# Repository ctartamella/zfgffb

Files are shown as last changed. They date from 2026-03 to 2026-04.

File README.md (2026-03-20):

# Team ZFG Active Pedal Design

This repository contains an amalgamation of DIY pedal designs from around the Internet to create a single optimal pedal design with thorough documentation and the most up to date feature set.

This includes:

* Gilphilbert V2 board
* XT30 connectors with simpler wiring
* 350W and 600W PSU options
* Multiple pedal options
* Complete BOM for all scenarios
* Easy to follow instructions

## Project Offerings

Included in this project's releases are a few key artifacts to help you build

* A full 3MF file for 3D printing including print settings.
* A full BOM covering various power supply and pedal options

Also included is a Wiki with full instructions to build this pedal for yourself.

## License

This design is licensed under CC BY-NC-SA 4.0.  This work would not be possible without the contributions of some very talented individuals.

* ChGri's orginal DIY FFB Pedal design [GitHub](https://github.com/ChrGri/DIY-Sim-Racing-FFB-Pedal)
* ChrisJamesChamp's design and wonderful documentation [GitHub](https://github.com/chrisjameschamp/DIY-Active-Pedal-Design)
* Gilphilbert's v2 PCB Designs [GitHub](https://github.com/gilphilbert/DIY-Sim-Racing-FFB-Pedal-PCBs)
* Additional modifications by Discord User Dud from the FFB Pedal [Discord](https://discord.com/channels/1113129142142120159/1390021016717361294)
* Custom CAD designs by ZFG member Alex Rich

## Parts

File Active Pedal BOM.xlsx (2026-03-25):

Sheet: Group Buy
Group | Part Name | Quantity Needed | Quantity per Unit | Total Needed | Units Needed | Cost | Subcost | Qty / Share
M3 | M3x0.5 5mm Flat | 2 | 50 | 14 | 1 | 7.29 | 7.29 | 7
 | M3x0.5 Insert | 15 | 100 | 105 | 2 | 8.69 | 17.38 | 28
 | M3x0.5 6mm SHCS | 4 | 120 | 28 | 1 | 7.99 | 7.99 | 17
 | M3x0.5 20mm SHCS | 2 | 100 | 14 | 1 | 6.96 | 6.96 | 14
 | M3x0.5 16mm Flat | 6 | 100 | 42 | 1 | 8.28 | 8.28 | 14
 | M3x0.5 14mm Flat head screw | 4 | 100 | 28 | 1 | 8.28 | 8.28 | 14
 | M3x0.5 18mm Flat head screw | 2 | 50 | 14 | 1 | 7.59 | 7.59 | 7
 | M3x0.5 30mm Flat | 1 | 100 | 7 | 1 | 8.68 | 8.68 | 14
 | M3 Square Nut | 2 | 200 | 14 | 1 | 6.99 | 6.99 | 28
 | M3x0.5 10mm Flat | 2 | 100 | 14 | 1 | 7.69 | 7.69 | 14
M4 | M4x0.7 Inserts | 12 | 50 | 84 | 2 | 9.99 | 19.98 | 14
 | M4x0.7 6mm Flat Head | 2 | 50 | 14 | 1 | 7.99 | 7.99 | 7
 | M4x0.7 14mm Flat Head | 16 | 100 | 112 | 2 | 9.49 | 18.98 | 28
 | M4x0.7 Nut | 4 | 100 | 28 | 1 | 5.69 | 5.69 | 14
 | M4x0.7 14mm Socket Head Screw | 2 | 120 | 14 | 1 | 8.99 | 8.99 | 17
 | M4x0.7 10mm Flat head screw | 10 | 50 | 70 | 2 | 6.89 | 13.78 | 14
 | M4x0.7 30mm Socket Head Screw | 2 | 50 | 14 | 1 | 8.46 | 8.46 | 7
M5 | M5x0.8 18mm SHCS | 2 | 50 | 14 | 1 | 8.86 | 8.86 | 7
 | M5x0.8 nut | 0 | 200 | 0 | 0 | 9.99 | 0 | 0
 | M5x08 40mm SHCS | 4 | 30 | 28 | 1 | 8.11 | 8.11 | 4
 | M5x0.8 Insert | 6 | 50 | 42 | 1 | 9.99 | 9.99 | 7
 | M5x0.8 14mm SHCS | 2 | 50 | 14 | 1 | 8.96 | 8.96 | 7
 | M5x0.8 45mm SHCS | 2 | 25 | 14 | 1 | 7.99 | 7.99 | 3
 | M5x0.8 16mm Flat Head | 2 | 50 | 14 | 1 | 8.28 | 8.28 | 7
 | M5 Steel Finish Washer | 2 | 30 | 14 | 1 | 9.99 | 9.99 | 4
M6 | M6 Nuts | 6 | 50 | 42 | 1 | 6.19 | 6.19 | 7
 | M6 Washers | 6 | 100 | 42 | 1 | 5.19 | 5.19 | 14
M8 | M8 Nylock Nut | 2 | 20 | 14 | 1 | 5.99 | 5.99 | 2
 | M8 15mm Button Head | 2 | 30 | 14 | 1 | 8.54 | 8.54 | 4
 | M8x1.25 18mm SHCS | 2 | 20 | 14 | 1 | 8.99 | 8.99 | 2
M2.5 | M2.5x0.4 6mm SHCS | 4 | 50 | 28 | 1 | 6.19 | 6.19 | 7
Misc | 608 ZZ Bearing | 6 | 20 | 42 | 3 | 6.99 | 20.97 | 8
 | 8mm x 40mm Dowel Pin | 1 | 10 | 7 | 1 | 9.69 | 9.69 | 1
 | 8mm OD 4.2mm ID 30mm spacer | 1 | 20 | 7 | 1 | 26 | 26 | 2
 | Silicon Tubing |  |  |  | 1 | 11.59 | 11.59
 | Number of Shares | 7 |  |  |  | SUB TOTAL | 342.52
 | Alex | 1 |  |  |  | TAX | 11.96
 | Chris | 3 |  |  |  | TOTAL | 354.48
 | Jeff | 3 |  |  |  | SHARE PRICE | 50.64

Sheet: Individual Purchases
Category | Part | Price | Quantity | Part Number | Notes | Link
Pedal | Linear rail (Brake) | 71 | 1 | JKK60-5-P-150-A1-F4-M | For the same price, getting the 5P version (5mm pitch aka moves 5mm per rotation) is fine | https://jlcmc.com/product/s/B16/BQD-JKK60/FA-%E7%9B%B4%E7%BA%BF%E8%BF%90%E5%8A%A8%E9%9B%B6%E4%BB%B6-%E9%92%A2%E5%88%B6%E7%9B%B4%E7%BA%BF%E6%A8%A1%E7%BB%84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
 | Linear rail (Throttle/Clutch) | 71 | 1 | JKK60-10-P-150-A1-F4-M | Note which is which however for SimHub setup as it is a parameter. | https://jlcmc.com/product/s/B16/BQD-JKK60/steel-linear-actuators-kk60-series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
 | 130w NEMA 23 Servo Motor | 82 | 1 | iSV57T-130S |  | https://www.omc-stepperonline.com/nema-23-integrated-easy-servo-motor-130w-3000rpm-0-45nm-63-73oz-in-20-50vdc-servo-motor-short-shaft-isv57t-130s
 | Load Cell | 47 | 1 | DYLY-107 200kg |  | https://a.co/d/eEIK39s
 | Aluminum base plate | 90 | 1 | SendCutSend | Cost listed was when buying 2. Buying just one will be a touch more.
350W PSU | MEANWELL LRS-350-36 | 39 |  |  | 350W PSU can support 1 and potentially 2 at your discretion | https://a.co/d/0a54GfQB
 | IEC Connector w/ Power Switch | 11 |  |  |  | https://www.mcmaster.com/5428N118/
600W PSU | IEC Connector w/ Power Switch | 11 |  |  | 600W PSU is required for 3 pedal setups. | https://www.mcmaster.com/5428N118/
 | MEANWELL LRS-600-36 | 60 |  |  |  | https://www.omc-stepperonline.com/lrs-600-36-mean-well-597-6w-36vdc-16-6a-115-230vac-enclosed-switching-power-supply-lrs-600-36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
Misc | XT 30 Wiring | 10 |  |  | You'll need pigtails for the PSU and to make custom cables depending on your setup.
 | 16 Gauge Wire | 10 |  |  | Daisy chaining is supported with the Gilphilbert boards, or you can go direct from PSU to pedal
 | Adhesive Silicon Roll | 10 | 1 |  |  | https://a.co/d/0RqzMVF
 | USB-C Extension | 10 | 1 |  |  | https://a.co/d/dT4IqKd
 | Heat Shrink Tubing
 | Dupont Wires/connector |  |  |  | Optional, but appears to be the cleanest way to connect wires to the stepper motor without soldering
Wifi | ESP32 Dev board for Wifi Bridge | 15 | 1 |  | Only 1 total is needed. | https://a.co/d/0eLUcZa6
 | RG178 U.FL MHF1 to SMA | 10 | 1 |  | 12 inch CAN work, but 14 is better albeit harder to find. | https://www.data-alliance.net/mhf1-to-rp-sma-female-cable-4-inch-6-8-10-12-14-inch-mhf1-mhf/
 | RP-SMA Male Antenna | 10 | 1 |  | 1 per pedal | https://a.co/d/09jSDpD9
Tools | Soldering Iron
 | Solder
 | Flux
 | Hammer |  |  |  | Tolerances were tight for me and this came in handy more than once.
Fasteners | M6x??? | 5 | 6 |  | Length depends on your mounting plate. 22.3mm is the length needed to reach the bottom of the plate. Add length as necessary.

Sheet: Filament Needed
Part | Classification | Filament Type | Weight Needed | Cost/Roll | Link
Pedal | Structural | PPA-CF | 1200 | 80 | https://a.co/d/01gsQgr3
Pedal | Decorative | PETG-CF | 600 | 20 | https://a.co/d/0c4b1sY0
350W PSU | All | Anything with reasonable heat resistance | 425
600W PSU | All | Anything with reasonable heat resistance | 500
 |  | For each pedal, print plates 1-6, then print pedal faces as needed (12 or 13 based on desired)
 |  | For WiFi support with the bridge, print plate 14
 |  | For 350W Power supply, print plates 7 and 8
 |  | For 600W power supply, print plates 9 and 10

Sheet: Links
 | Has Wiki with info? | Web | Discord
ChrGri's Orginal FFB Pedal Design | YES | https://github.com/ChrGri/DIY-Sim-Racing-FFB-Pedal | https://discord.gg/zTfQaxpAUz
ChrisJamesChamp's Build | YES | https://github.com/chrisjameschamp/DIY-Active-Pedal-Design | https://discord.com/channels/1113129142142120159/1350718069441429504
Dud's Build |  |  | https://discord.com/channels/1113129142142120159/1390021016717361294
Gilphilbert v2 Board | YES | https://github.com/gilphilbert/DIY-Sim-Racing-FFB-Pedal-PCBs
350W XT30 Support |  | https://makerworld.com/en/models/2140438-350w-power-supply-cover-with-xt30-connector
Simucube Pedal Design |  | https://docs.simucube.com/ActivePedal/Drawings.html
Wifi Bridge Case |  | https://makerworld.com/en/models/1456361-esp32-s3-wroom-case?from=search#profileId-1517915

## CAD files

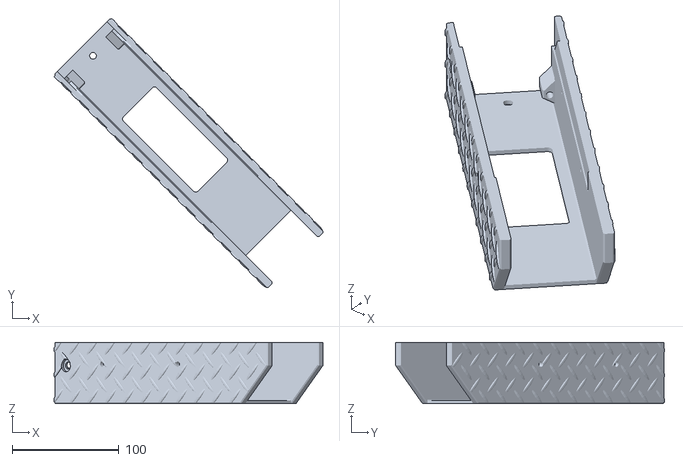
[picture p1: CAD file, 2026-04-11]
External Case/Main Cover.stl
251.5 x 251.4 x 57.5

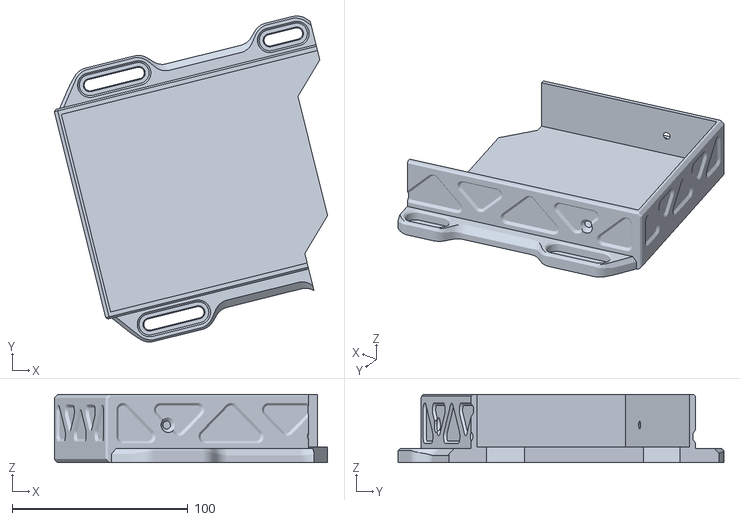
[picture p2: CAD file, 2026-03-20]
350W PSU/350W PSU IO Cover.stl
155.7 x 185.7 x 38.9

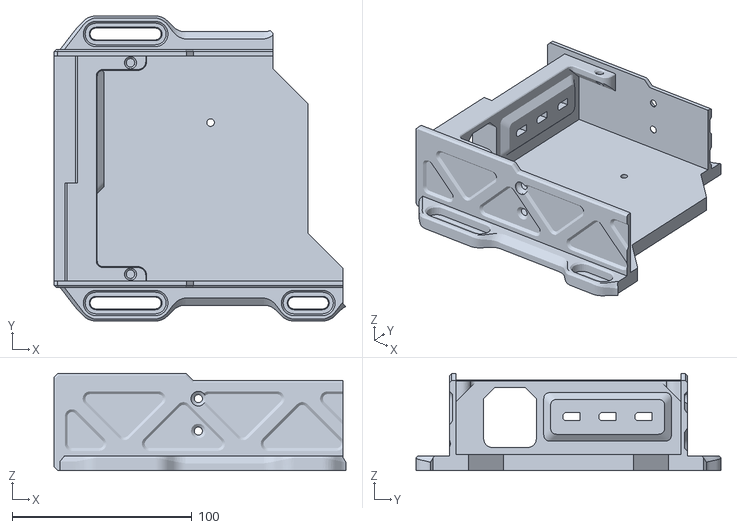
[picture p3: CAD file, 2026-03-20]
600W PSU/600W PSU Case Lower.stl
162.2 x 169.5 x 53.9

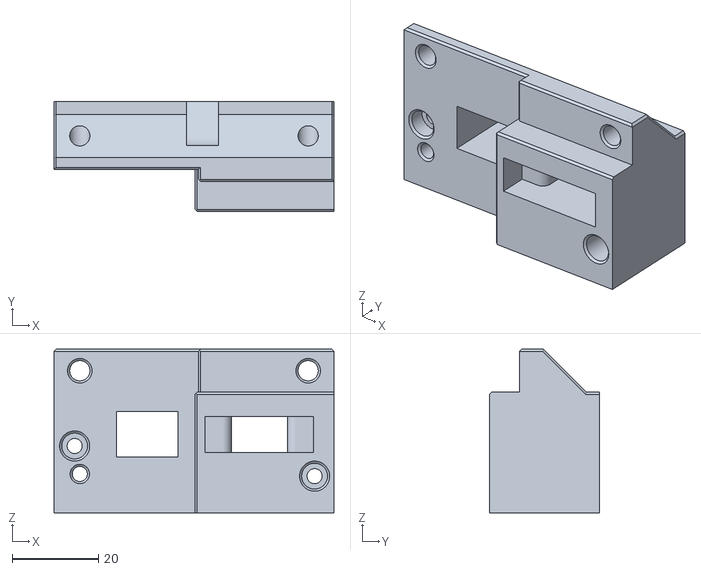
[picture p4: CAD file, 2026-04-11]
External Case/Inner IO Bracket.stl
65.1 x 25.6 x 38.0

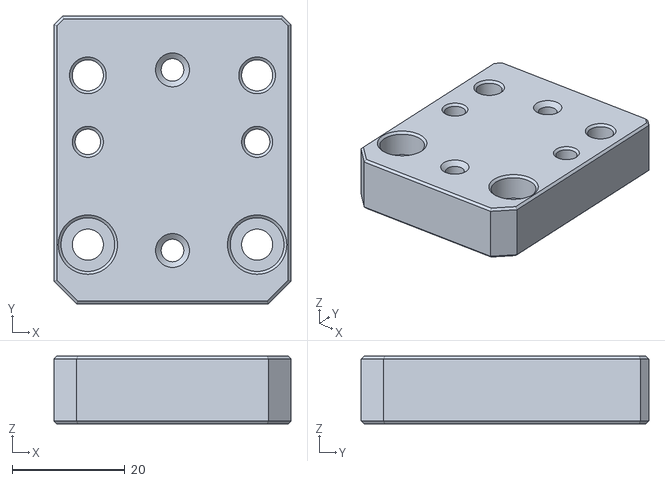
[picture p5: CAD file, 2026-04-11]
Load Cell Assembly/Sled Mount.stl
42.0 x 51.0 x 12.0

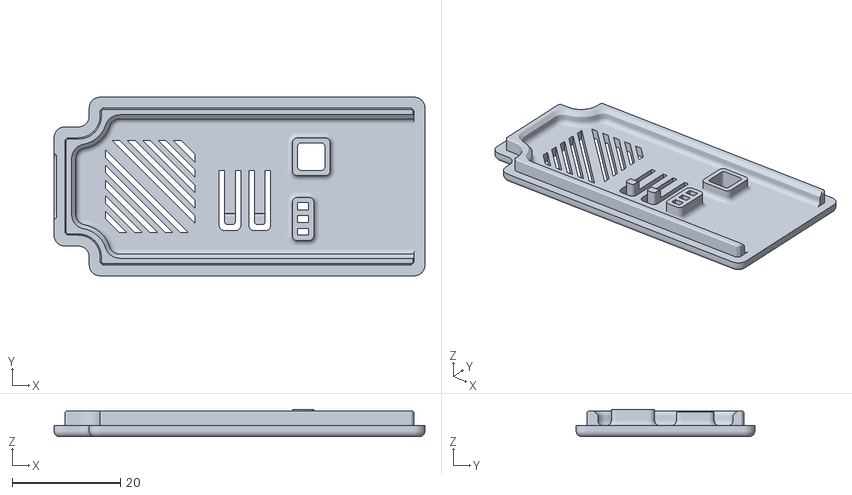
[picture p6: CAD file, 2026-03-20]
Miscellaneous/ESP32_S3_WROOM_Case Bottom.stl
68.5 x 33.0 x 5.00

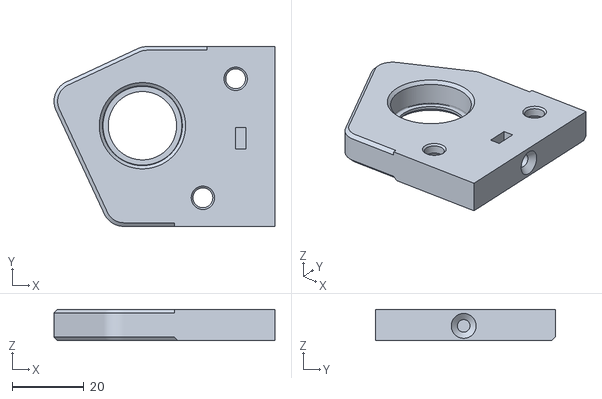
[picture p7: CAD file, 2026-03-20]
Pedal Arm/Right Pedal Arm Bracket.stl
61.5 x 50.0 x 8.75

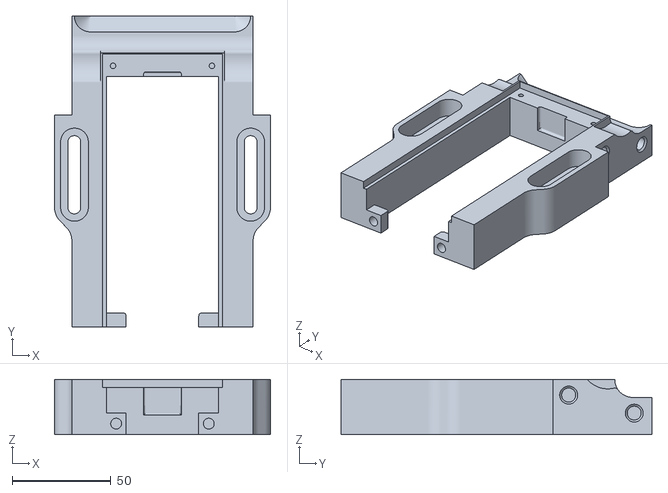
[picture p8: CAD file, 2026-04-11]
Pedal Base/Front Pedal Base.stl
109.1 x 157.1 x 28.0

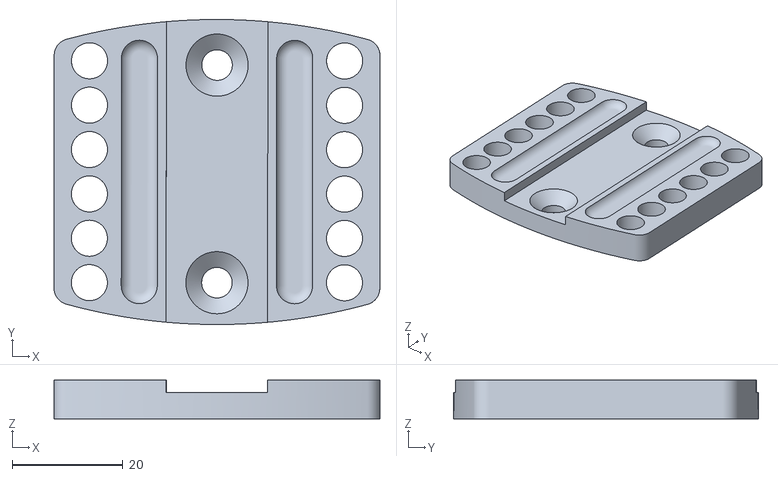
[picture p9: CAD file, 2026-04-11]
Pedal Faces/Simucube Pedal Adapter.stl
58.8 x 55.0 x 7.02

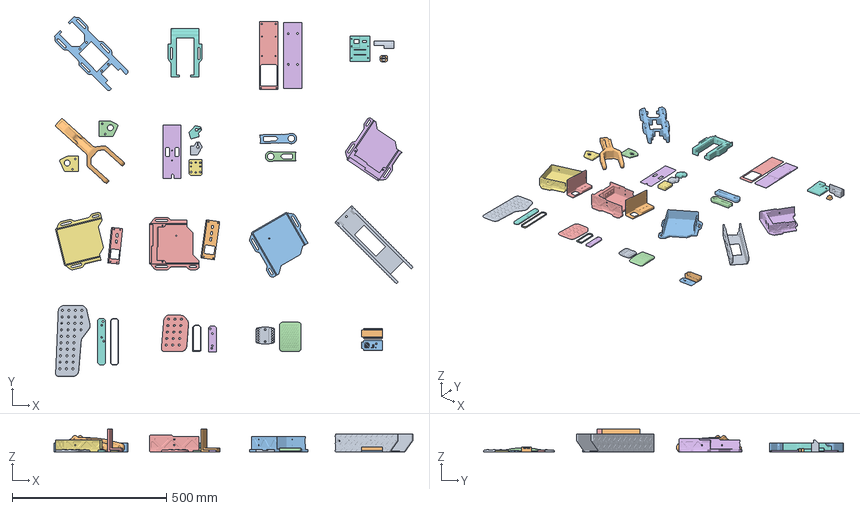
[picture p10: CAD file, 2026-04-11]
ZFG Pedal Build.3mf
1160.8 x 1165.3 x 73.5 mm
cover 2.stl x 2
IOCover XT30.STEP
600w_PSU_Case_Rear_V1.stl
BrakeClutch_Beauty_Ring_V1.stl
BrakeClutch_Pedal_Face_V1.stl
Brake_Mounting_Bracket_V1.stl
Throttle_Beauty_Ring_V1.stl
Throttle_Mounting_Bracket_V1.stl
Throttle_Pedal_Face_V1.stl
Pedal_V3.step
back base (bolt version).stl
left base bearing.stl
pcb holder.stl
rail under support.stl
right base bearing.stl
io bracket 2.stl
io bracket.stl
xt30.stl
Load_Cell_Arm_V1.stl_A
Load_Cell_Arm_V1.stl_B
obj_1_Körper1.stl
obj_2_Körper2.stl
obj_3_Körper3.stl
slider arm connector.stl_A
slider arm connector.stl_B
ESP32_S3_WROOM_Case.stl_1.stl
ESP32_S3_WROOM_Case.stl_2.stl
ActivePedal 2023 pedal face 3d model.step
600W PSU Cover Body XT30.STEP
slider.stl
Front base dip switch pocket.STEP
Simucube Pedal Adapter.STEP

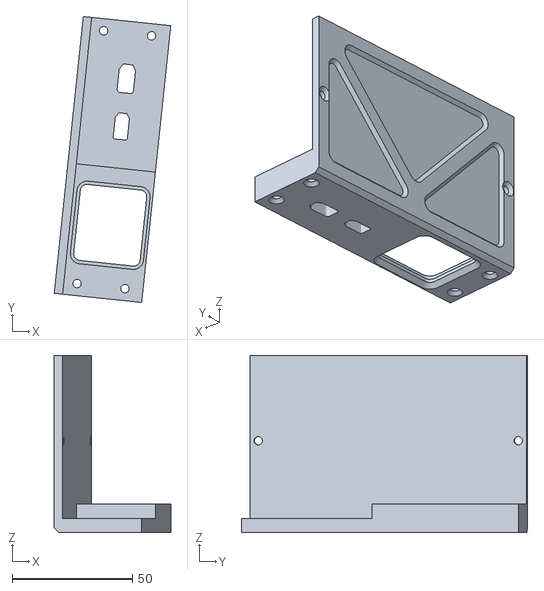
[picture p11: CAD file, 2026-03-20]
350W PSU/350W PSU Case Lower.stl
48.4 x 118.7 x 73.5

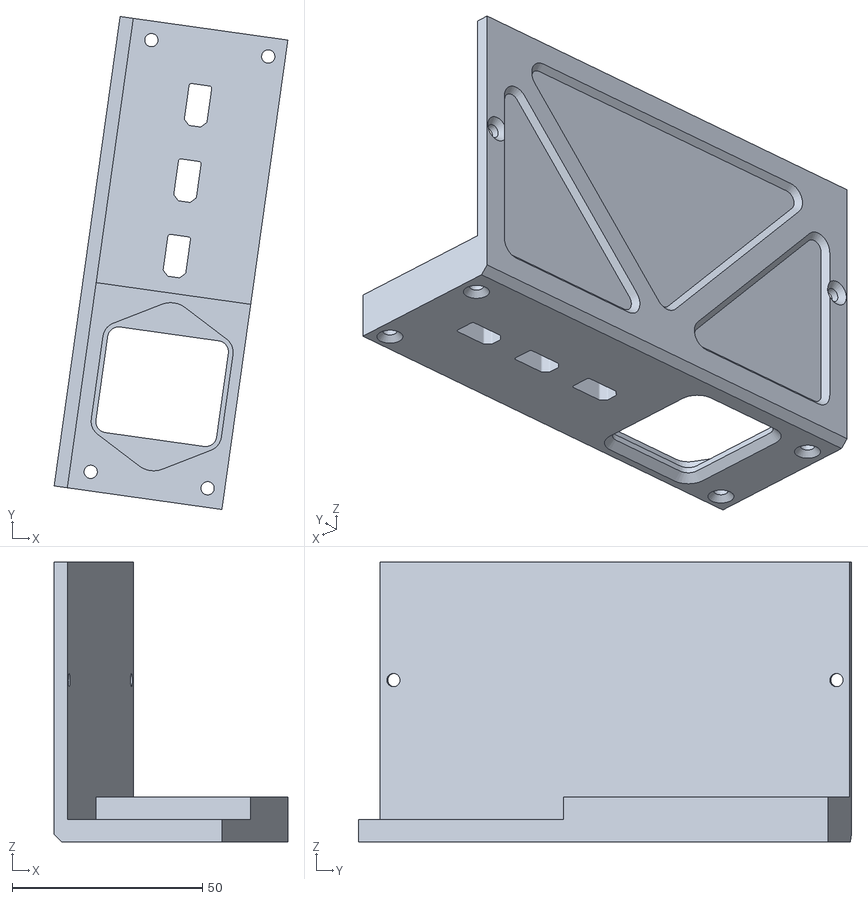
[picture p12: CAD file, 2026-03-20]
600W PSU/600W PSU IO Cover.stl
61.4 x 129.5 x 73.5

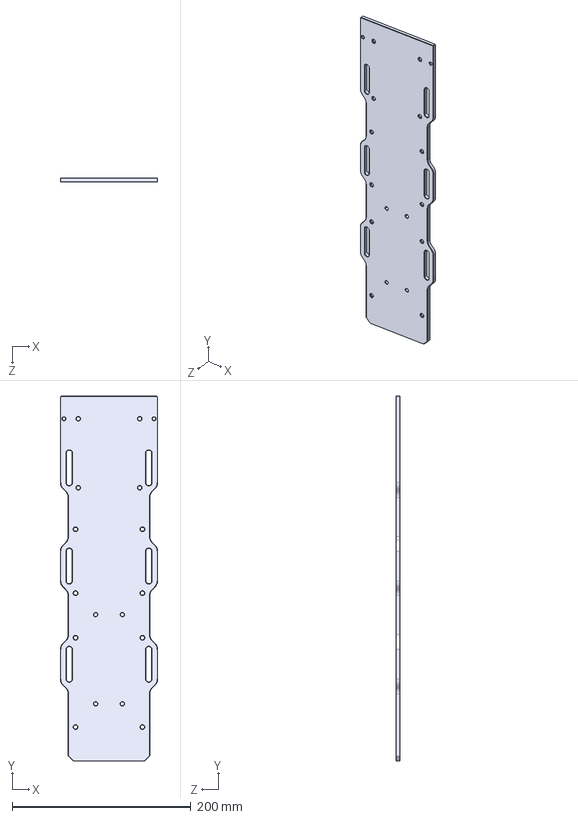
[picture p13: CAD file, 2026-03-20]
Aluminum Base Plate.STEP
109.1 x 408.9 x 4.75 mm

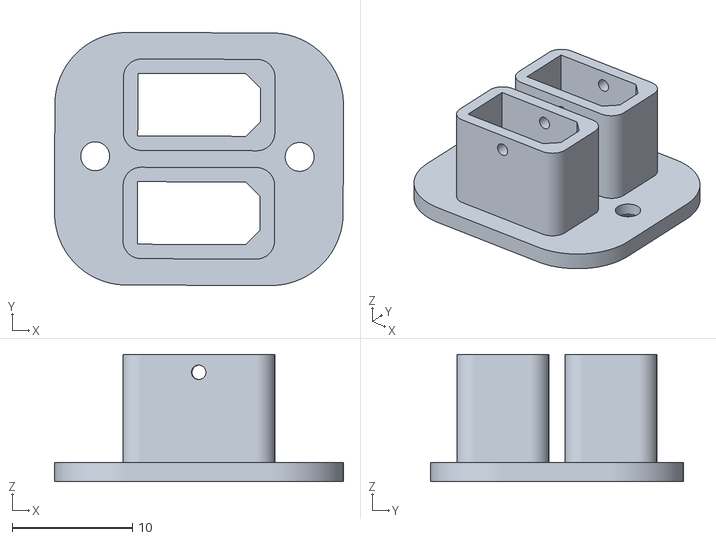
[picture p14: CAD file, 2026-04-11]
External Case/XT30 Insert.stl
24.0 x 21.0 x 10.6

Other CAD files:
Load Cell Assembly/Slider Connector B.stl
Miscellaneous/ESP32_S3_WROOM_Case Top.stl
Pedal Arm/Left Pedal Arm Bracket.stl
Pedal Base/Rear Pedal Base.stl
350W PSU/350W PSU Case Upper.stl
600W PSU/600W PSU Case Upper.stl
External Case/Outer IO Bracket.stl
Load Cell Assembly/Dust Cover.stl
Load Cell Assembly/Load Cell Arm A.stl
Load Cell Assembly/Load Cell Arm B.stl
Load Cell Assembly/Slider Connector A.stl
Pedal Arm/Pedal Arm.stl
Pedal Base/PCB Holder Plate.stl
Pedal Base/Rail Support Plate.stl
Pedal Faces/ActivePedal Ultimate Pedal Face.stl
Pedal Faces/CJC Brake Clutch Adapter.stl
Pedal Faces/CJC Brake Clutch Beauty Ring.stl
Pedal Faces/CJC Brake Clutch Pedal Face.stl
Pedal Faces/CJC Throttle Adapter.stl
Pedal Faces/CJC Throttle Beauty Ring.stl
Pedal Faces/CJC Throttle Pedal Face.stl

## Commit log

2026-03-20 First project commit.
    [350W PSU Case Lower.stl, 350W PSU Case Upper.stl, 350W PSU IO Cover.stl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]
2026-03-20 Add 3mf file.
    [ZFG Pedal Build.3mf]
2026-03-25 Updated BOM and print file.
    [Active Pedal BOM.xlsx, ZFG Pedal Build.3mf]
2026-04-11 Updated STLs and 3mf.
    [Front Pedal Base.stl, Inner IO Bracket.stl, Main Cover.stl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]
